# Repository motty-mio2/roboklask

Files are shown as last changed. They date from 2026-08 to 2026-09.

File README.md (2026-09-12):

# 🏓 Roboklask: Autonomous AI-Powered Klask-Playing Robot

English | [日本語](./README_ja.md)







Roboklask is an autonomous, real-time robotics system designed to play **Klask**—a fast-paced, magnetic table hockey game. Combining high-speed computer vision, an ONNX-optimized reinforcement learning agent (PPO), and low-latency motor control, Roboklask plays autonomously against human opponents.

[**👉 日本語版のREADMEはこちら (README_ja.md)**](./README_ja.md)

---

## 📸 Demo & Hardware Overview

*(Place your robot gameplay video or GIF here!)*
Roboklask Table and Striker Concept

### The Hardware Setup
* **Structure**: Custom 2D H-bot XY Gantry.
* **Actuators**: High-torque NEMA 17 Stepper Motors driven by DRV8825 motor drivers (configured at 1/8 microstepping).
* **Brain**: Arduino UNO R4 WiFi running Zephyr RTOS.
* **Vision**: OAK-D (DepthAI) or Intel RealSense stereo cameras capturing the table dynamics at 30+ FPS.

---

## ✨ Features

- 🧠 **PPO Reinforcement Learning**: Runs real-time inference on a Proximal Policy Optimization model (`klask_ppo_model.onnx`) via ONNX Runtime to make movement decisions.
- ⚡ **Low-Latency step control**: Powered by Zephyr RTOS, achieving step frequencies of up to **16,000 steps/sec** with **25,600 steps/sec²** acceleration.
- 🔌 **Unified MessagePack-RPC**: Low-overhead serial communication running at 30Hz, passing targets and receiving coordinate feedback synchronously.
- 🎯 **Robust Computer Vision**: Real-time HSV-based blue color tracking that automatically calibrates itself to detect the board, ball, and striker under dark lighting conditions.
- 🛡️ **Auto-Recalibration**: Dynamic limit switch detection (`resetX`/`resetY`) that recalibrates coordinate origins on the fly without stopping the game.

---

## 🛠️ System Architecture

```mermaid
graph TD
    A[Camera: OAK-D / RealSense] -->|Raw Video Frames| B(Python Vision Tracker)
    B -->|HSV Coordinate Extraction| C(Motion Policy: Ball Tracking / PPO Model)
    C -->|Target Coords: X,Y | D(McuConnection / BridgeDriver)
    D -->|MessagePack-RPC @ 30Hz| E[Arduino UNO R4 WiFi / Zephyr RTOS]
    E -->|High Frequency step pulses| F[Motors: NEMA 17 / DRV8825]
    E -->|Encoder Feedback @ 30Hz| D
```

> [!TIP]
> For a detailed look at our RTOS optimizations, serial-buffer flushing, and kinematics math, see the **[Technical Optimizations & Engineering Details](./docs/optimizations.md)** document.

---

## 💻 Quickstart (Arduino App Lab)

Simply open this project in Arduino App Lab!

## 🛠️ Alternative Setup (For Debugging / Development)

This project uses [mise](https://mise.jdx.dev/) as a polyglot task runner and environment manager.

### 1. Installation
Clone the repository and sync python dependencies:
```sh
git clone https://github.com/motty-mio2/roboklask.git
cd roboklask/python
uv sync
```

### 2. Compile and Upload Firmware
Compile the C++ Arduino sketch:
```sh
cd ../sketch
mise run build
```

### 3. Run the AI Agent
Start the vision loop (requires a camera and serial connection):
```sh
cd ../python
uv run python run_vision.py
```

### 4. Run Formatting & Lints
Keep the codebase clean:
```sh
mise run format   # Format Python & C++ source files
mise run lint     # Strict C++ static analysis and python type checks
```

---

## 📁 Repository Structure

- **[`sketch/`](./sketch/)** — Arduino C++ firmware targeting Arduino UNO R4 (UNO Q / Minima) for dual stepper motor control and sensor integration.
- **[`python/`](./python/)** — Python companion app (Python 3.13) for vision tracking (OAK-D / RealSense), motion policy inference (PPO / Ball tracking), and web UI.
- **[`hardware/`](./hardware/)** — 3D printable mechanical parts and mount designs.
  - **[Hardware & 3D Printing Guide](./hardware/HardWare.md)** ([日本語版](./hardware/HardWare_ja.md))
- **[`docs/`](./docs/)** — Technical engineering documentation and RTOS optimization details.

## 📚 Documentation

- **[Hardware & 3D Printing Guide](./hardware/HardWare.md)**: STL files, recommended BambuLab P1S print settings, and parts list.
- **[Python Package Documentation](./python/README.md)**: Setup and usage for the vision tracking and motion control application.
- **[Technical Optimizations & Engineering Details](./docs/optimizations.md)**: RTOS optimizations, serial-buffer flushing, and kinematics math.

## 🔗 Related Repositories

- [Klask_PCB](https://github.com/motty-mio2/Klask_PCB): Custom designed shield for Arduino UNO Q
- [Klask Vision](https://github.com/motty-mio2/Klask_vision): Computer vision inference package for Klask
  - [Klask Vision Learning](https://github.com/motty-mio2/Klask_vision_learning): Training pipeline for Klask vision models
- [Klask RL](https://github.com/motty-mio2/Klask_RL): Reinforcement learning agent for Klask

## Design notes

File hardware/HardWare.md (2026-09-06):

# Hardware

[English](HardWare.md) | [日本語](HardWare_ja.md)

This document provides information on 3D-printable hardware models and printing guidelines.  
The images show the **recommended print orientation** on the build plate in the slicer.

## Recommended Print Settings (BambuLab P1S)

All parts, except for the motor mounts, can be printed using the common settings.

### 1. Common Settings (All parts except Motor Mounts)

Based on the Bambu Studio standard preset **`0.20mm Standard`** with support enabled.

- **Recommended Material**: PLA
- **Base Preset**: `0.20mm Standard`
- **Supports**:
  - **Enable Support**: ON
  - **Type**: **Tree**
  *(Automatic tree support ensures stable printing even for parts with overhangs)*

### 2. Motor Mount Settings

Uses the Bambu Studio standard preset **`0.20mm Strength`**. Wall loops and infill density are preconfigured for structural strength.

- **Recommended Material**: PETG or ABS (recommended due to motor clamping torque, vibrations, and mechanical stress)
- **Base Preset**: `0.20mm Strength`
- **Supports**:
  - **Enable Support**: ON (Tree support recommended)
  - Using Bambu Lab support filament (e.g., Support for PLA/PETG) makes the interface layer easy to remove and ensures a clean finish.

---

## 3D Printed Parts List

| Part Name | File |  Qty  | Print Setting (Preset) | Notes |
| :--- | :--- | :---: | :---: | :--- |
| **RealSense Mount** | [RealSenseMounter.stl](./RealSenseMounter.stl) | 1 | 0.20mm Standard (Tree) | No support needed |
| **Camera Holder Jig**  | [CameraAngle.stl](./CameraAngle.stl) | 2 | 0.20mm Standard (Tree) | No support needed |
| **Motor Mount L** | [MotorMount_L.stl](./MotorMount_L.stl) | 1 |  **0.20mm Strength** | PETG/ABS recommended, support material recommended |
| **Motor Mount R** | [MotorMount_R.stl](./MotorMount_R.stl) | 1 |  **0.20mm Strength** | PETG/ABS recommended, support material recommended |
| **Leg** | [Leg.stl](./Leg.stl) | 2 | 0.20mm Standard (Tree) | No support needed |
| **Limit Switch Mount** | [LimitSwitchMount.stl](./LimitSwitchMount.stl) | 1 | 0.20mm Standard (Tree) | No support needed |
| **Pulley Mount A_L** | [PulleyMountA_L.stl](./PulleyMountA_L.stl) | 1 | 0.20mm Standard (Tree) | - |
| **Pulley Mount A_R** | [PulleyMountA_R.stl](./PulleyMountA_R.stl) | 1 | 0.20mm Standard (Tree) | - |
| **Pulley Mount B** | [PulleyMountB.stl](./PulleyMountB.stl) | 1 | 0.20mm Standard (Tree) | - |
| **Pulley Mount C** | [PulleyMountC.stl](./PulleyMountC.stl) | 1 | 0.20mm Standard (Tree) | - |
| **Arm Holder** | [Arm_Holder.stl](./Arm_Holder.stl) | 1 | 0.20mm Standard (Tree) | Significant supports, support material strongly recommended |
| **Stopper** | [Stopper.stl](./Stopper.stl) | 2 | 0.20mm Standard (Tree) | No support needed |

---

## Part Details

### Camera

- [RealSense Mount](./RealSenseMounter.stl)
  - Quantity: 1
  - Setting: Common Settings
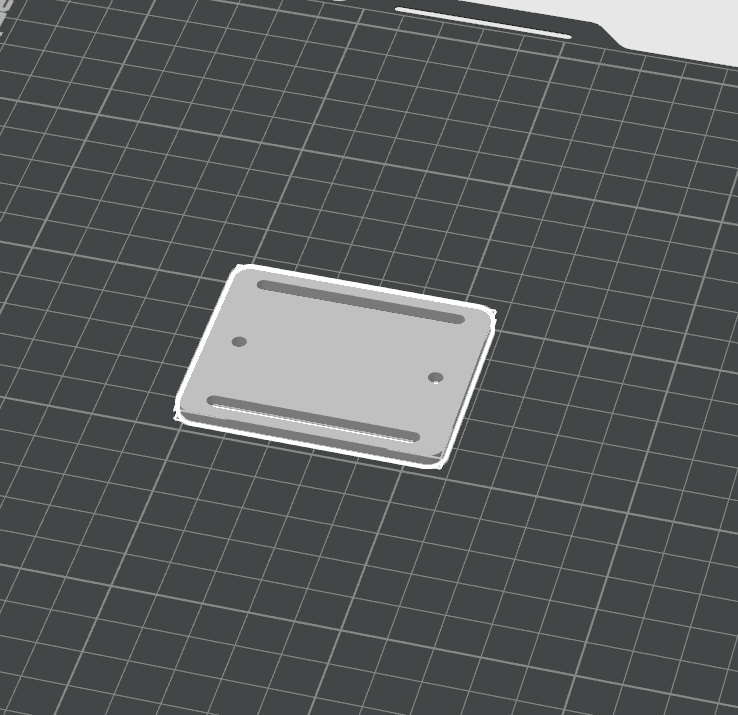
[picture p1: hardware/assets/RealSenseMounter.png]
RealSense Mount
  
  
- [Camera Holder Jig](./CameraAngle.stl)
  - Quantity: 2
  - Setting: Common Settings
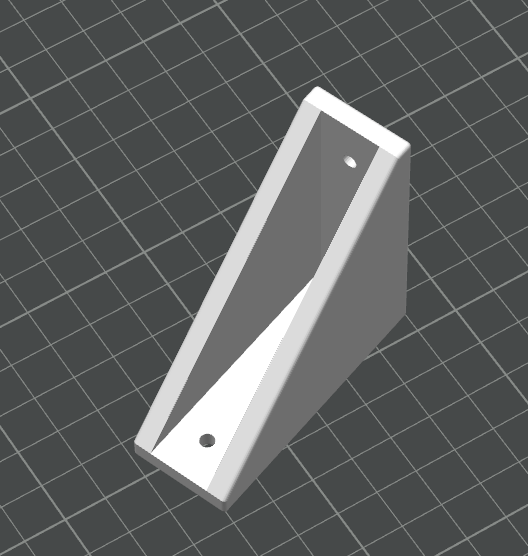
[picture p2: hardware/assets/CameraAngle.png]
Camera Holder Jig
  
  
### Main Body

- Motor Mounts
  - [MotorMount_L.stl](./MotorMount_L.stl) (Left: 1)
  - [MotorMount_R.stl](./MotorMount_R.stl) (Right: 1)
  - Setting: **Motor Mount Settings (0.20mm Strength)**
  - Due to mechanical load, we recommend higher infill density or strong filament such as ABS or PETG.
  - Using Bambu Lab support filament helps achieve a clean finish.
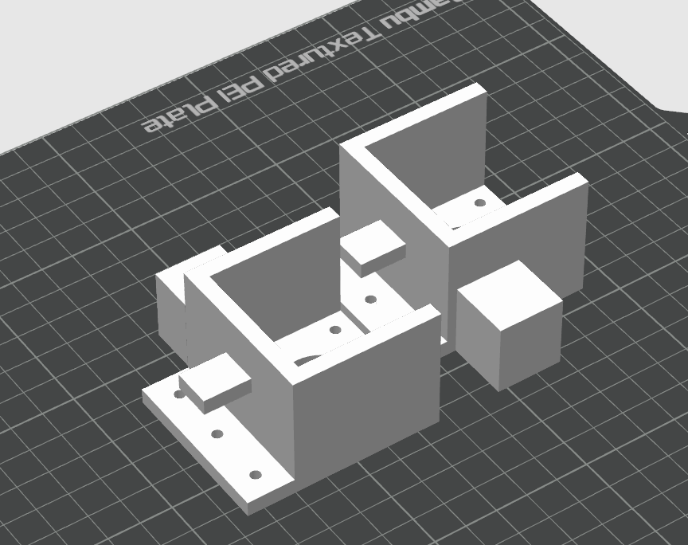
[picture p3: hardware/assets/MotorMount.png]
Motor Mount
  
  
- [Leg](./Leg.stl)
  - Quantity: 2
  - Setting: Common Settings
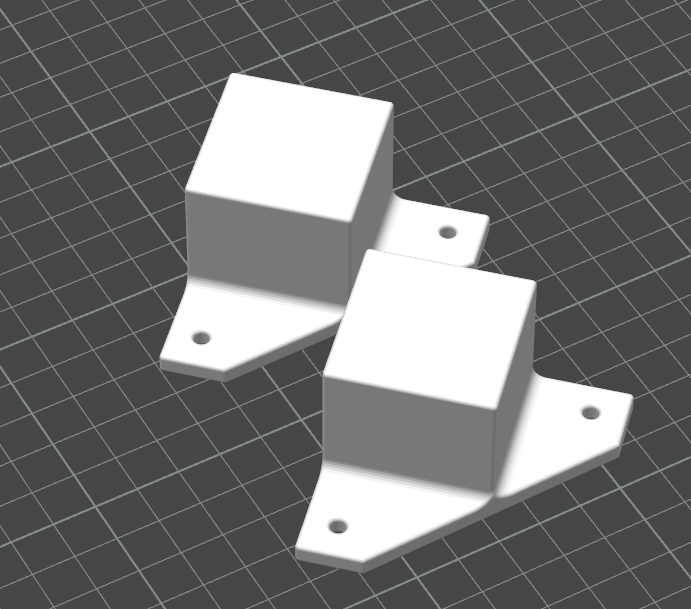
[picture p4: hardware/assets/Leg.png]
Leg
  
  
- [Limit Switch Mount](./LimitSwitchMount.stl)
  - Quantity: 1
  - Setting: Common Settings
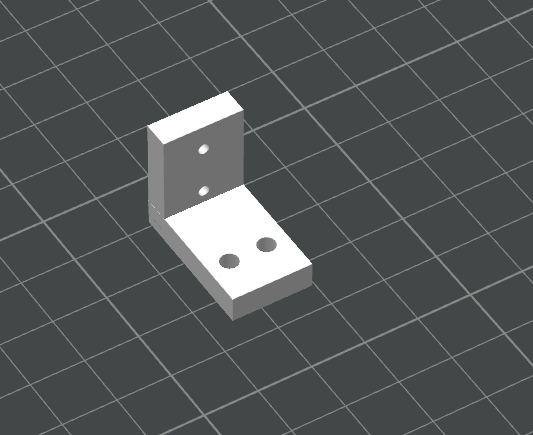
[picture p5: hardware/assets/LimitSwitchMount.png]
Limit Switch Mount
  
  
- Pulley Mounts
  - [PulleyMountA_L.stl](./PulleyMountA_L.stl) (1)
  - [PulleyMountA_R.stl](./PulleyMountA_R.stl) (1)
  - [PulleyMountB.stl](./PulleyMountB.stl) (1)
  - [PulleyMountC.stl](./PulleyMountC.stl) (1)
  - Setting: Common Settings
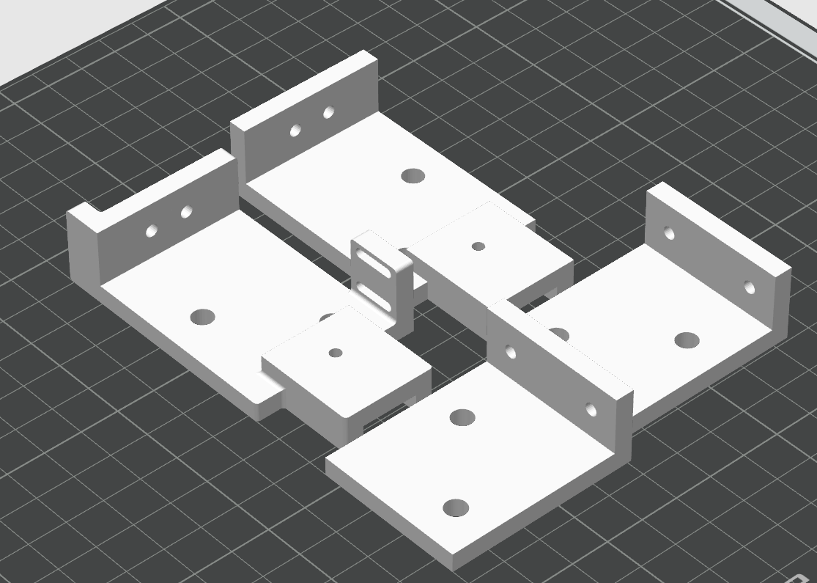
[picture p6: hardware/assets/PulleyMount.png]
Pulley Mount
  
  
- [Arm Holder](./Arm_Holder.stl)
  - Quantity: 1
  - Setting: Common Settings
  - Generates a large amount of supports.
  - Support filament is strongly recommended.
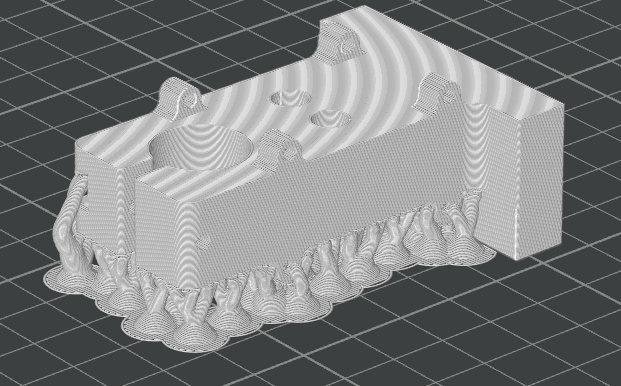
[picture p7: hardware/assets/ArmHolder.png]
Arm Holder
  
  
- [Stopper](./Stopper.stl)
  - Quantity: 2
  - Setting: Common Settings
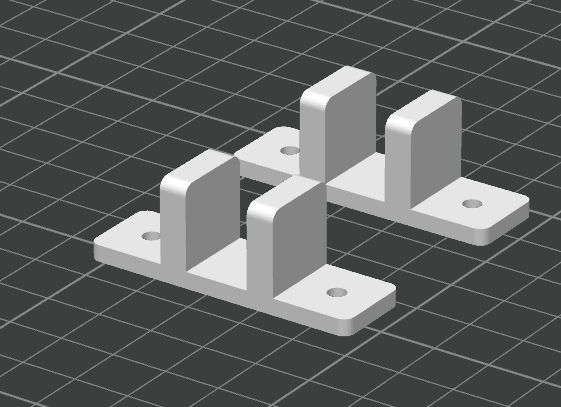
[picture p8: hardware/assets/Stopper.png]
Stopper


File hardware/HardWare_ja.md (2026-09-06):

# ハードウェアについて

[English](HardWare.md) | [日本語](HardWare_ja.md)

ここには、3Dプリントするハードウェアのモデルデータおよび印刷情報を記載します。  
掲載している各パーツの画像は、スライサーでの**推奨する印刷の向き**を示しています。

## 推奨印刷設定（BambuLab P1S）

モータマウンタ以外のパーツは、すべて共通の設定で印刷可能です。

### 1. 共通設定（モータマウンタ以外）

Bambu Studio の標準プリセット **`0.20mm Standard`** をベースにし、サポート設定のみ追加しています。

- **推奨素材**: PLA
- **ベースプリセット**: `0.20mm Standard`
- **サポート**:
  - **サポート有効化**: ON
  - **タイプ**: **ツリー（Tree）**
  *(※オーバーハングがある形状も自動ツリーサポートで安定して印刷できます)*

### 2. モータマウンタ設定

Bambu Studio の標準プリセット **`0.20mm Strength`** を使用します。壁ループ数やインフィルがあらかじめ強度重視に設定されています。

- **推奨素材**: PETG または ABS（モータの締め付けや振動・負荷がかかるため高強度フィラメントを推奨）
- **ベースプリセット**: `0.20mm Strength`
- **サポート**:
  - **サポート有効化**: ON（ツリーサポート推奨）
  - BambuLabのサポート用フィラメント（Support for PLA/PETG等）を使用すると、インターフェース層が剥がしやすく美しく仕上がります

---

## 3Dプリントパーツ一覧

| 部品名 | ファイル | 数量  |  印刷設定（プリセット）  | 特記事項 |
| :--- | :--- | :---: | :---: | :--- |
| **RealSenseマウンタ** | [RealSenseMounter.stl](./RealSenseMounter.stl) | 1 | 0.20mm Standard (ツリー) | サポート不要 |
| **カメラホルダー治具** | [CameraAngle.stl](./CameraAngle.stl) | 2 | 0.20mm Standard (ツリー) | サポート不要 |
| **モータマウンタ L** | [MotorMount_L.stl](./MotorMount_L.stl) | 1 | **0.20mm Strength** | PETG/ABS推奨・サポート材推奨 |
| **モータマウンタ R** | [MotorMount_R.stl](./MotorMount_R.stl) | 1 | **0.20mm Strength** | PETG/ABS推奨・サポート材推奨 |
| **脚** | [Leg.stl](./Leg.stl) | 2 | 0.20mm Standard (ツリー) | サポート不要 |
| **リミットスイッチマウント** | [LimitSwitchMount.stl](./LimitSwitchMount.stl) | 1 | 0.20mm Standard (ツリー) | サポート不要 |
| **プーリーマウント A_L** | [PulleyMountA_L.stl](./PulleyMountA_L.stl) | 1 | 0.20mm Standard (ツリー) | - |
| **プーリーマウント A_R** | [PulleyMountA_R.stl](./PulleyMountA_R.stl) | 1 | 0.20mm Standard (ツリー) | - |
| **プーリーマウント B** | [PulleyMountB.stl](./PulleyMountB.stl) | 1 | 0.20mm Standard (ツリー) | - |
| **プーリーマウント C** | [PulleyMountC.stl](./PulleyMountC.stl) | 1 | 0.20mm Standard (ツリー) | - |
| **アームホルダー** | [Arm_Holder.stl](./Arm_Holder.stl) | 1 | 0.20mm Standard (ツリー) | サポート多・サポート材推奨 |
| **ストッパー** | [Stopper.stl](./Stopper.stl) | 2 | 0.20mm Standard (ツリー) | サポート不要 |

---

## 各パーツ詳細

### カメラ系

- [RealSenseマウンタ](./RealSenseMounter.stl)
  - 数量: 1つ
  - 設定: 共通設定
  RealSenseマウンタ
  
- [カメラホルダー治具](./CameraAngle.stl)
  - 数量: 2つ
  - 設定: 共通設定
  カメラホルダー治具
  
### 本体系

- モータマウンタ
  - [MotorMount_L.stl](./MotorMount_L.stl) (L側: 1つ)
  - [MotorMount_R.stl](./MotorMount_R.stl) (R側: 1つ)
  - 設定: **モータマウンタ設定（0.20mm Strength）**
  - 力がかかるため、インフィル密度を高くするか、ABSやPETGなどの強度のあるフィラメントを使用することを推奨します
  - BambuLabのサポート用フィラメントがあると美しく仕上がります
  モータマウンタ
  
- [脚](./Leg.stl)
  - 数量: 2つ
  - 設定: 共通設定
  脚
  
- [リミットスイッチマウント](./LimitSwitchMount.stl)
  - 数量: 1つ
  - 設定: 共通設定
  リミットスイッチマウント
  
- プーリーマウント
  - [PulleyMountA_L.stl](./PulleyMountA_L.stl) (1つ)
  - [PulleyMountA_R.stl](./PulleyMountA_R.stl) (1つ)
  - [PulleyMountB.stl](./PulleyMountB.stl) (1つ)
  - [PulleyMountC.stl](./PulleyMountC.stl) (1つ)
  - 設定: 共通設定
  プーリーマウント
  
- [アームホルダー](./Arm_Holder.stl)
  - 数量: 1つ
  - 設定: 共通設定
  - サポートの分量が非常に多くなります
  - サポート用フィラメントの使用を強く推奨します
  アームホルダー
  
- [ストッパー](./Stopper.stl)
  - 数量: 2つ
  - 設定: 共通設定
  ストッパー

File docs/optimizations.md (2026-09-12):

# Roboklask: Technical Optimizations & Engineering Details

This document covers the deep technical optimizations implemented in the Roboklask firmware, communication bridge, and runtime scheduler.

---

## 1. High-Frequency Step Generation (Zephyr RTOS)

### The Challenge
Standard Arduino environments run `loop()` sequentially. In RTOS-based cores (like Zephyr RTOS on Arduino UNO R4), returning from `loop()` triggers system-level thread rescheduling, serial polling, and hardware events. This introduces a background overhead of **200µs to 1ms** per iteration.

Because `AccelStepper` relies on a polling architecture (`stepper.run()`), it must be called at a frequency higher than the required step pulse frequency. With a target operational speed of **16,000 steps/second** (at 1/8 microstepping), the minimum polling frequency must exceed **30kHz**. Polling inside a standard `loop()` limited to 1kHz due to core overhead restricts the motor speed to a crawl (under 2,000 steps/sec).

### The Optimization
We bypassed the Arduino core's `loop()` return overhead by encapsulating the execution inside an internal infinite `while(true)` loop:

```cpp
void loop() {
  unsigned long last_yield_ms = 0;

  while (true) {
    // 1. Poll stepper motors at max CPU frequency (~100kHz)
    xyControl.run();

    unsigned long current_time = millis();

    // 2. Manage 33ms control cycles with guard clauses
    if (current_time - last_update_ms < CYCLE_ms) {
      #if defined(ARDUINO_UNO_Q)
      if (Serial1.available() > 0) {
        safeUpdate();
      }
      // Thread Starvation Guard: Yield exactly once per millisecond
      if (current_time - last_yield_ms >= 1) {
        last_yield_ms = current_time;
        k_yield();
      }
      #endif
      continue;
    }
    last_update_ms = current_time;

    // 3. Execute 33ms periodic logic (target coordinates, matrix rendering)
    ...
  }
}
```

* **Result**: Step polling frequency increased from ~1kHz to **~100kHz**, unlocking the full potential of the NEMA 17 steppers to run smoothly at **16,000 steps/sec** with an acceleration profile of **25,600 steps/sec²**.
* **Thread Safety**: Calling `k_yield()` once every 1ms ensures that Zephyr's network and system threads get their time slices, preventing any hardware lockups.

---

## 2. Low-Latency RPC over MessagePack-RPC

### The Challenge
Initially, the Python tracker sent separate RPC notifications for target striker positions (`py2mcu`) and target ball positions (`ball`) at 30Hz. This generated **60 packets/second** over the 115200bps serial port. The overhead of serial packet parsing and deserialization on the MCU created a queue bottleneck: when the python sender stopped, the robot continued to move for several seconds (queued command latency).

### The Optimization
1. **Consolidated Payload**: We merged the target coordinate and the ball coordinates into a single MessagePack-RPC call:
   ```python
   # Python Driver
   self.bridge.notify("py2mcu", target.x, target.y, ball.x, ball.y)
   ```
2. **Synchronous Buffer Flushing (`safeUpdate`)**: Instead of relying on Zephyr's asynchronous service thread to deserialize packets, the main loop detects data in the buffer (`Serial1.available() > 0`) and triggers `safeUpdate()` synchronously.
3. **Step-Level Change Detection**:
   Floating-point coordinate values fluctuate slightly due to camera noise (e.g., `0.0001` variance). Overwriting the target via `stepper.moveTo()` resets AccelStepper's acceleration planner. We wrapped the target setter to only execute `moveTo()` when the actual physical target steps change:
   ```cpp
   long target_s1 = (target_step_x + target_step_y) * resolution;
   long target_s2 = (-target_step_x + target_step_y) * resolution;

   if (target_s1 != last_target_s1 || target_s2 != last_target_s2) {
     stepper1.moveTo(target_s1);
     stepper2.moveTo(target_s2);
     last_target_s1 = target_s1;
     last_target_s2 = target_s2;
   }
   ```
* **Result**: Latency accumulation is completely eliminated. The robot tracking response matches the 33ms vision loop instantaneously.

---

## 3. Kinetic Safety & Boundary Calibration

### The Challenge
Homing absolute coordinates via raw step offsets can lead to physical limit switch crashes if the two motors run slightly out of sync. Furthermore, keeping the striker away from physical limit walls reduces its playable range.

### The Optimization
* **Relative Target Homing**: Homing steps are commanded via relative movements (`move()`) rather than absolute targets (`moveTo()`). This guarantees that both H-bot motors receive identical step pulses, keeping the carriage perfectly straight during homing.
* **Separation of Safety Margins**:
  We separated the physical release limit (`PHYSICAL_BACK = 300` steps) from the software play boundary limit (`STEP_BACK_X`, `STEP_BACK_Y = 100` steps).
  ```cpp
  constexpr int XSTEP = 3100 * 2 + 500 - STEP_BACK_X * 2;
  constexpr int YSTEP = 1500 * 2 + 100 - STEP_BACK_Y;
  ```
  This maximizes the playable area (`XSTEP=2900`, `YSTEP=1400`) while allowing the robot to calibrate its zero-point exactly `100` steps away from the physical switches.
* **Dynamic Recalibration & Non-Blocking Escape**: If a limit switch is triggered mid-game, the robot immediately stops and executes a backing-off routine (`escapeX/Y` by `PHYSICAL_BACK` steps). During this backing-off `while` loop, the code actively processes serial communications (`safeUpdate()`) and yields thread control (`k_yield()`) to prevent the Zephyr RTOS communication stacks from starving and dropping the connection. Afterwards, the MCU recalculates and overrides the absolute coordinates on the fly (`resetX/Y`) seamlessly.

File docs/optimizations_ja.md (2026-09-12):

# Roboklask: 技術解説 ＆ 最適化詳細

本文書では、Roboklask のファームウェア、通信ブリッジ、およびランタイムスケジューラに実装されている深い技術的最適化について解説します。

---

## 1. Zephyr RTOS 上での極限の超低遅延・高頻度ステップパルス生成

### 課題
標準の Arduino 環境は、単一スレッドで `loop()` をシーケンシャルにループ実行します。しかし、Zephyr RTOS などの OS 上で動作する Arduino コア（Arduino UNO R4 WiFi など）では、`loop()` が `return` して再実行されるまでの間に、システムスレッドの再スケジューリング、シリアルポートのポーリング、その他のハードウェア管理など、**200µs〜1ms 程度のオーバーヘッド**が発生します。

ステップ更新ライブラリ `AccelStepper` は、ポーリング制御モデル（`stepper.run()`）を採用しているため、目標のステップ出力周波数よりも大幅に高い頻度でポーリングする必要があります。1/8ステップ解像度で最大速度 **16,000 steps/sec** を出すためには、最低でも **30kHz 以上**の頻度で `run()` を呼ぶ必要があります。しかし、コアのオーバーヘッドのせいで `loop()` の周回が 1kHz 程度に制限されると、モーター速度は 2,000 steps/sec 未満（這うような遅さ）に頭打ちになってしまいます。

### 解決策
`loop()` の `return` に伴う Arduino コア側のオーバーヘッドを完全に回避するため、`loop()` の内部を **`while(true)` による無限ポーリングループ** にリファクタリングしました。

```cpp
void loop() {
  unsigned long last_yield_ms = 0;

  while (true) {
    // 1. CPUの限界周波数（約100kHz）でステッピングモーターを更新
    xyControl.run();

    unsigned long current_time = millis();

    // 2. 33msに満たない場合は、即座に continue してループ先頭に戻る
    if (current_time - last_update_ms < CYCLE_ms) {
      #if defined(ARDUINO_UNO_Q)
      if (Serial1.available() > 0) {
        safeUpdate();
      }
      // スレッド飢餓防止ガード: 1msに1回だけ OS に処理を明け渡す
      if (current_time - last_yield_ms >= 1) {
        last_yield_ms = current_time;
        k_yield();
      }
      #endif
      continue;
    }
    last_update_ms = current_time;

    // 3. 33ms 周期のメイン制御処理を実行
    ...
  }
}
```

* **結果**: ステップのポーリング周波数が ~1kHz から **~100kHz** へと跳ね上がり、NEMA 17 ステッピングモーターの限界値である **`16,000 steps/sec` (秒速約200mm) の最高速度** と、**`25,600 steps/sec²` の加速度** を一切引っかかることなく滑らかに引き出せるようになりました。
* **スレッド安全性**: 1msに1回だけ `k_yield()` を呼び出すことで、Zephyr RTOS のネットワークやシリアル処理のシステムタスクが確実に実行時間を割り当てられ、ハングアップを完璧に防止しています。

---

## 2. MessagePack-RPC を介した低遅延 RPC 通信の実現

### 課題
当初、Python側のトラッカーは、目標ストライカー座標（`py2mcu`）と目標ボール座標（`ball`）を別々の RPC 通知として 30Hz 周期で送信していました。これは、115200bps のシリアル通信回線上で **毎秒 60 パケット** を処理することを意味します。マイコン側でのパケット受信・デシリアライズ処理のオーバーヘッドにより受信バッファにパケットが滞留し、Python側の送信を停止してもしばらくロボットが遅れて動き続ける「キューイング遅延（数秒レベル）」が発生していました。

### 解決策
1. **パケットの統合**: 目標座標とボール座標を単一の MessagePack-RPC 呼び出しに統合し、通信パケット数を半減させました。
   ```python
   # Python Driver
   self.bridge.notify("py2mcu", target.x, target.y, ball.x, ball.y)
   ```
2. **同期バッファフラッシュ (`safeUpdate`)**: 非同期スレッドのタスク切り替えによる受信遅延を防ぐため、メインループ内でシリアルデータがあること (`Serial1.available() > 0`) を検知し、同期的に `safeUpdate()` を実行するようにしました。
3. **ステップ数レベルの変化検知フィルタ**:
   カメラの画像認識ノイズ（`0.0001` 程度の微小な座標変動）によって毎サイクル目標座標が書き換わると、`stepper.moveTo()` を呼ぶたびに `AccelStepper` の加減速プロファイルプランナーが再計算されてリセットされてしまいます。これを防ぐため、物理的な「目標ステップ数」が実際に変化したときだけ `moveTo()` を呼ぶガードをクラス内部に組み込みました。
   ```cpp
   long target_s1 = (target_step_x + target_step_y) * resolution;
   long target_s2 = (-target_step_x + target_step_y) * resolution;

   if (target_s1 != last_target_s1 || target_s2 != last_target_s2) {
     stepper1.moveTo(target_s1);
     stepper2.moveTo(target_s2);
     last_target_s1 = target_s1;
     last_target_s2 = target_s2;
   }
   ```
* **結果**: 通信起因の遅延が完全に消失し、ロボットの追従性が Python 側の 33ms 制御周期と完全に同期するようになりました。

---

## 3. 安全機構（Kinetic Safety） ＆ 境界キャリブレーション

### 課題
H-bot リンク機構において、絶対座標の指定のみでホーミングを行うと、左右のモーターのパルス出力のわずかな非対称によってキャリッジが斜めに傾き、リミットスイッチに衝突するリスクがあります。また、壁からの安全マージンが大きすぎると、ストライカーの盤面での可動域が狭くなってしまいます。

### 解決策
* **相対座標によるホーミング**: ホーミング時の移動には絶対座標指定（`moveTo`）ではなく、相対座標（`move()`）を使用しました。これにより、2つのモーターに完全に同一のステップパルス数が供給され、キャリッジが一切傾くことなくまっすぐ前後に直進します。
* **物理限界とソフト境界マージンの分離**:
  スイッチ衝突から安全に離脱するための物理的な戻り量（`PHYSICAL_BACK = 300` ステップ）と、ゲームのプレイ境界を制限するソフトウェアマージン（`STEP_BACK_X`/`Y = 100` ステップ）を分離定義しました。
  ```cpp
  constexpr int XSTEP = 3100 * 2 + 500 - STEP_BACK_X * 2;
  constexpr int YSTEP = 1500 * 2 + 100 - STEP_BACK_Y;
  ```
  これにより、ソフトウェア原点 `0` はスイッチから 100 ステップ離れた安全な位置にありつつ、プレイ領域自体は限界の広さ（`XSTEP=2900`, `YSTEP=1400`）を確保することができました。
* **動的再キャリブレーション ＆ ノンブロッキング離脱**: プレイ中に激突を検知した場合、システムをシャットダウンするのではなく、安全方向への退避動作（`PHYSICAL_BACK`ステップ分の `escapeX/Y` 移動）を実行します。この退避中の `while` ループ内でもシリアル通信の処理（`safeUpdate()`）と RTOS のスレッド明け渡し（`k_yield()`）を継続して実行することで、退避移動中も Python 側との通信切断やハングを完全に防止しています。離脱完了後、その場で絶対座標を動的に再計算して `setCurrentPosition()` で上書きし、ゲームを中断せずに復帰します。

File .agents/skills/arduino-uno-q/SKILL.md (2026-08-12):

---
name: arduino-uno-q
description: Arduino UNO Q (UNO R4 / Minima) ボード開発、MPU-MCU間の通信、App Lab、App Bricks、および Bridge API についての知識と手順を提供します。
---

# SKILL.md: Arduino UNO Q

## 概要
このスキルは、Arduino UNO Q ボードにおける開発基盤、特に Linux マイクロプロセッサ (MPU) と Arduino マイクロコントローラ (MCU) 間を連携させる Bridge API、およびボード固有の実装手順を提供します。

---

## 1. 接続方式の選択 (UNO Q vs Minima)
本プロジェクトでは、対象となるターゲットボードに応じて通信および運動制御ポリシーのレイヤーが異なります。

* **UNO R4 (UNO Q / Zephyr RTOS)**:
  * **通信方式**: `Bridge` 通信 (MessagePack RPC)
  * **設定**: `KLASK_OUTPUT_TYPE=bridge`
  * **特徴**: Zephyr RTOS カーネル上で動作し、LEDマトリクス表示、および Bridge API による非同期・同期RPCを利用します。
* **Minima (Arduino UNO R4 Minima)**:
  * **通信方式**: UART シリアル通信 (115200 baud)
  * **設定**: `KLASK_OUTPUT_TYPE=uart`
  * **特徴**: リアルタイム処理ループで UART の特定ヘッダー (`0xAA`) に基づくバイナリパケットを直接処理します。

---

## 2. MCU 側 (C++ スケッチ) の Bridge 実装手順

UNO Q で Bridge 通信を行う場合、以下の手順とテンプレートに従って実装します。

### 実装テンプレート
```cpp
#include <Arduino_RouterBridge.h>
#include <zephyr/kernel.h> // Zephyr カーネルのヘッダー

// 共有データアクセス用のミューテックスを定義
K_MUTEX_DEFINE(xy_mutex);

struct Position {
  float x;
  float y;
} new_head_pos, head_pos;

unsigned long lastReportMs = 0;

void setup() {
  // Bridge APIの初期化
  Bridge.begin();

  // Python(MPU)側から呼び出されるRPC/通知のコールバック登録
  Bridge.provide("xy", [](float x, float y) {
    // コールバックは別スレッドで実行されるため、必ずロックを取得する
    k_mutex_lock(&xy_mutex, K_FOREVER);
    new_head_pos.x = x;
    new_head_pos.y = y;
    k_mutex_unlock(&xy_mutex);
  });

  Monitor.begin();
}

void loop() {
  // 共有変数を安全にローカルにコピーして利用する
  Position local_target;
  k_mutex_lock(&xy_mutex, K_FOREVER);
  local_target = new_head_pos;
  k_mutex_unlock(&xy_mutex);

  // 運動制御への適用など
  // xyControl.move(local_target);

  // Python(MPU)側への周期的な座標通知 (非ブロッキングで20ms周期を維持)
  unsigned long now = millis();
  if (now - lastReportMs >= 20) {
    lastReportMs = now;
    // MPU側の report_xy プロバイダを呼び出す
    Bridge.call("report_xy", head_pos.x, head_pos.y);
  }
}
```

### 【重要】マルチスレッドとスレッドセーフティ
* **RPC コールバックのスレッド**: `Bridge.provide` で登録されたコールバックは、メインの `loop()` とは異なるスレッド（Bridge サービススレッド）で実行されます。
* **排他制御**: `loop()` 内とコールバック内で共有されるすべての変数（例: ターゲット座標など）は、Zephyr カーネルのプリミティブである `K_MUTEX_DEFINE` マクロで定義した `k_mutex` を用いて、`k_mutex_lock` および `k_mutex_unlock` で保護してください。

---

## 3. MPU 側 (Python) の Bridge 実装手順

Python アプリケーション側では、`arduino-app-bricks` に含まれる Bridge API を使用して接続モジュールを実装します。

### 実装テンプレート (`bridge_connection.py` 相当)
```python
import threading
from arduino.app_utils import Bridge
from python.domain import RobotXY
from python.domain.mcu_connection import McuConnection

class BridgeMcuConnection(McuConnection):
    def __init__(self) -> None:
        self._lock = threading.Lock()
        self._latest_feedback: RobotXY | None = None

    def start(self) -> None:
        try:
            # MCUからの report_xy 呼び出しを処理するコールバックを登録
            Bridge.provide("report_xy", self._on_feedback)
        except Exception as e:
            print(f"Error starting bridge: {e}")

    def _on_feedback(self, x: float, y: float) -> None:
        # コールバックはサブスレッドから呼び出されるため threading.Lock で保護
        feedback = RobotXY(x=x, y=y)
        with self._lock:
            self._latest_feedback = feedback

    def send_target(self, target: RobotXY | None) -> None:
        if target is None:
            return
        try:
            # メインの画像処理・推論ループをブロックしないために notify (非同期RPC) を使用
            Bridge.notify("xy", target.x, target.y)
        except Exception as e:
            print(f"Error sending coordinates: {e}")

    def read_feedback(self) -> RobotXY | None:
        with self._lock:
            feedback = self._latest_feedback
            self._latest_feedback = None  # 読み取り後はリセット
        return feedback

    def stop(self) -> None:
        try:
            # コールバックの登録解除
            Bridge.unprovide("report_xy")
        except Exception as e:
            print(f"Error stopping bridge: {e}")
```

### 実装時の注意点
1. **ブロッキングの回避**: 座標送信には `Bridge.call` ではなく `Bridge.notify` を使用してください。`call` は応答を待機するため、20ms などの高速な画像処理ループ（メインスレッド）を停止させ、ジッターを発生させる原因になります。
2. **メッセージバッファ制限**: `arduino-router` 経由の RPC 送信メッセージサイズは最大 **256バイト** です。大量のデータや複雑な構造体を一度に送信しないでください。

---

## 4. リファレンスとドキュメント
* [Working with Arduino Router RPC | Arduino Documentation](https://docs.arduino.cc/tutorials/uno-q/routerbridge-multilanguage/)
* [Bridge API Reference | Arduino Documentation](https://docs.arduino.cc/software/app-lab/bridge/bridge-api/)
* [GitHub - arduino/app-bricks-examples](https://github.com/arduino/app-bricks-examples)

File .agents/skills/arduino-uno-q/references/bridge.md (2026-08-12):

# SKILL: Arduino UNO Q Bridge API

## 概要
Arduino UNO QのBridge APIは、Linuxマイクロプロセッサ（MPU）上のPythonロジックと、Arduinoマイクロコントローラ（MCU）上のリアルタイムなC++スケッチ間で双方向通信（RPC）を行うためのレイヤーです [1]。裏側では`arduino-router`サービスがMessagePack RPCプロトコルを用いてネットワークを管理しており、通信時の最大メッセージサイズは256バイトに制限されています [2]。

## API仕様詳細と制約

### 1. C++ API (MCU / Arduinoスケッチ側)
実装には `<Bridge.h>` をインクルードして使用します [3]。
*   **初期化**: `setup()` 関数内で他のBridgeメソッドを使用する前に `Bridge.begin()` を呼び出し、内部のシリアルトランスポートを初期化します [3]。
*   **送信 (Python関数の呼び出し)**:
    *   `Bridge.call("メソッド名", 引数...)`: Linux側の登録された関数を呼び出し、結果が返るまで実行をブロック（待機）します [3]。
    *   `Bridge.notify("メソッド名", 引数...)`: 応答を待たずに非同期でデータを送信（Fire-and-forget）します [4]。256バイトを超えたメッセージは破棄されます [4]。
*   **受信 (関数の公開)**:
    *   `Bridge.provide("名前", コールバック)`: 高優先度のバックグラウンドRPCスレッドで実行される関数を登録します [4]。処理は短くスレッドセーフである必要があります [4]。**警告**: デッドロックを防ぐため、このコールバック内部で `Bridge.call()` や `Monitor.print()` を使用してはいけません [5]。
    *   `Bridge.register("名前", コールバック)`: メインの `loop()` コンテキスト内で実行される関数を登録します [5]。`delay()` や `Wire` などの標準Arduino APIと連携する場合は、クラッシュを防ぐためにこちらを使用してください [5, 6]。

### 2. Python API (MPU / Linux側)
`bridge` モジュールから `Bridge` クラスをインポートして使用します [6]。
*   **送信 (MCU関数の呼び出し)**:
    *   `Bridge.call("メソッド名", 引数...)`: MCU側の関数を呼び出し、結果をブロックして待機します [6]。256バイト制限を超えると例外が発生します [6]。
    *   `Bridge.notify("メソッド名", 引数...)`: MCUの関数へ、応答を待たずに非同期で送信します [7]。
*   **受信 (関数の公開)**:
    *   `Bridge.register("タグ", コールバック)`: MCUからの要求に一致するタグを受け取った際に呼び出されるPython関数を登録します [7]。

### 3. データ型のマッピング (MsgPack)
Bridgeライブラリは、PythonとC++間のデータ型をMsgPackを使用して自動的にシリアライズ・デシリアライズします [8]。
*   Python `list` ⇔ C++ `std::vector`, `std::array`, `std::list` [8]
*   Python `dict` ⇔ C++ `std::map` [8]
*   Python `str` ⇔ C++ `char*`, `String` [8]
*   Python `bytes` ⇔ C++ `std::vector<uint8_t>`, `arduino::msgpack::arr_t<uint8_t>` [8]
*   Python `None` ⇔ C++ `void` [8]

### 4. Monitor API
従来のUSB CDCシリアルポート（`Serial.print`など）の代わりに、仮想シリアルモニターとして機能する Monitor API を使用します [8]。
*   `Monitor.begin()` で初期化します [9]。
*   `Monitor.print(データ)` や `Monitor.println(データ)` でシリアルモニターへデータを送信します [9]。
*   `Monitor.read()` で受信データを読み取りますが、現在のC++実装ではキューが空の場合、標準のStreamクラスと異なり **`-1` ではなく `0` を返す**仕様に注意してください [9]。

## References
*   [Bridge API Reference | Arduino Documentation](https://docs.arduino.cc/software/app-lab/bridge/bridge-api/)
*   [Working with Arduino Router RPC | Arduino Documentation](https://docs.arduino.cc/tutorials/uno-q/rou

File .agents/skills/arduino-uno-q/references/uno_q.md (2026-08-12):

# SKILL: Arduino UNO Q デバイス概要

## デバイスの概要
**Arduino UNO Q**は、高レベルな処理を担うLinuxマイクロプロセッサ（MPU）と、リアルタイム制御を担うArduinoマイクロコントローラ（MCU）を1つのボードに統合したシングルボードコンピュータです。このデュアルアーキテクチャプラットフォームにより、AIエッジアプリケーションなどに必要な高性能コンピューティングと、決定論的なリアルタイムハードウェア制御を同時に実現します。両プロセッサ間は、内蔵のRPCライブラリ（Arduino Bridge）とバックグラウンドで稼働する `arduino-router` デーモンによってシームレスに連携しています。

## プロセッサ (MPU / MCU)
UNO Qは、それぞれ以下の高性能な専用プロセッサを搭載しています。

*   **MPU (Microprocessor Unit)**: **Qualcomm Dragonwing™ QRB2210**
    *   **仕様**: Quad-core Arm® Cortex®-A53 (2.0 GHz)。
    *   **特徴**: Adreno GPU 3Dグラフィックスアクセラレータ、デュアルISP (13 MP + 13 MP または 25 MP @ 30 fps) などを備えています。主にPythonアプリケーション、AIモデル、高度なロジック処理を担います。
*   **MCU (Microcontroller Unit)**: **STMicroelectronics STM32U585**
    *   **仕様**: 32-bit Arm® Cortex®-M33 (最大 160 MHz)。
    *   **特徴**: 2 MBのフラッシュメモリ、786 kBのSRAM、浮動小数点演算ユニット（FPU）を搭載しています。センサーからのデータ読み取りやモーター制御など、リアルタイムなArduinoスケッチ（C++）を遅延なく実行します。

## オペレーティングシステム (OS)
*   **MPU側 (Linux)**: **Debian Linux OS**。
    MPU上では、アップストリームサポートを備えた**完全なDebianベースのLinux環境**が組み込まれて稼働しています。開発者は馴染みのあるLinux環境でそのまま開発を行うことが可能であり、スタンドアロンのPCのようにも扱えます。
    *※注意: ソース文献内では単に「Debian Linux」とのみ記載されており、ご指定の「Debian 13」という具体的なメジャーバージョンについては言及されていません。*
*   **MCU側 (Arduino / Zephyr)**: **Zephyr OS**。
    MCU側にデプロイされるArduinoスケッチは、**リアルタイムOSであるZephyr OS上で動作**します。これにより、クリティカルなタイミングが要求される処理を確実に実行できます。

## References
*   [UNO Q | Arduino Documentation](https://docs.arduino.cc/hardware/uno-q)
*   [Working with Arduino Router RPC | Arduino Documentation](https://docs.arduino.cc/tutorials/uno-q/routerbridge-multilanguage/)

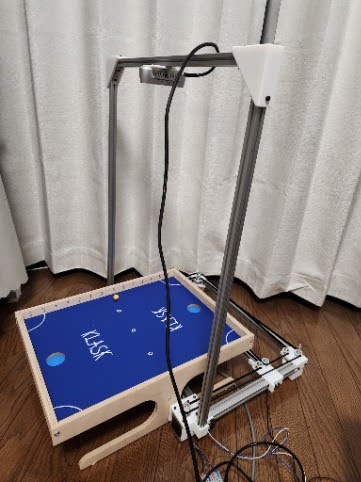
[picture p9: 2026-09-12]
assets/roboklask.jpg

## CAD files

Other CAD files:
hardware/LimitSwitchMount.stl
hardware/CameraAngle.stl
hardware/Arm_Holder.stl
hardware/MotorMount_L.stl
hardware/PulleyMountA_L.stl
hardware/PulleyMountB.stl
hardware/Stopper.stl
hardware/RealSenseMounter.stl
hardware/Leg.stl
hardware/PulleyMountC.stl
hardware/MotorMount_R.stl
hardware/PulleyMountA_R.stl

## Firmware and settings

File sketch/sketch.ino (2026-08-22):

#include <AccelStepper.h>
#if defined(ARDUINO_UNO_Q)
#include <Arduino_RouterBridge.h>
#include <zephyr/kernel.h>

#include "matrix.h"
Arduino_LED_Matrix matrix;
K_MUTEX_DEFINE(head_mutex);
K_MUTEX_DEFINE(ball_mutex);
#elif defined(ARDUINO_MINIMA)
#include "serial_bridge.hpp"
SerialBridge bridge(Serial, 115200);
#endif

#include <vector>

#include "pinout.h"
#include "xycontrol.hpp"

XYControl xyControl(MX_STEP, MX_DIR, MY_STEP, MY_DIR, SW_X, SW_Y);

Position new_head_pos;
Position head_pos;
Position ball_pos; // 追加: loopでの描画用

void blinkLED(int count) {
  for (int i = 0; i < count; i++) {
    digitalWrite(LED_BUILTIN, LOW); // 点灯 (LOW=ON)
    delay(100);
    digitalWrite(LED_BUILTIN, HIGH); // 消灯 (HIGH=OFF)
    delay(100);
  }
  delay(500);
}

unsigned long now = 0;
unsigned long last_update_ms = 0;
constexpr uint8_t CYCLE_ms = 33;

void setup() {
  // 1. 最優先でLEDピンを初期化して消灯(HIGH=OFF)にする
  pinMode(LED_BUILTIN, OUTPUT);
  digitalWrite(LED_BUILTIN, HIGH);

  // PC接続用シリアルデバッグの開始
  Serial.begin(115200);
  for (int i = 0; i < 10 && !Serial; i++) {
    delay(100);
  }
  Serial.println("MCU Started.");

  blinkLED(1); // 1回点滅: setup開始成功 (消灯で終了)

#if defined(ARDUINO_UNO_Q)
  // LED Matrixの初期化のみ最初に行う
  matrix.begin();
  matrix.setGrayscaleBits(1);
  matrix.clear();
#endif

  pinMode(SW_X, INPUT_PULLUP);
  pinMode(SW_Y, INPUT_PULLUP);

  pinMode(nEN, OUTPUT);
  digitalWrite(nEN, HIGH);

  // M0, M1, M2ピンの出力を明示的に設定
  pinMode(M0, OUTPUT);
  digitalWrite(M0, setM0);
  pinMode(M1, OUTPUT);
  digitalWrite(M1, setM1);
  pinMode(M2, OUTPUT);
  digitalWrite(M2, setM2);

  blinkLED(2); // 2回点滅: ピン初期設定完了、Homing直前

  // 2. キャリブレーションの実行
  digitalWrite(LED_BUILTIN, LOW); // Homing開始: 点灯 (LOW=ON)
  Serial.println("Starting homing...");
  xyControl.homing();
  digitalWrite(LED_BUILTIN, HIGH); // Homing完了: 消灯 (HIGH=OFF)
  Serial.println("Homing finished.");

  // 四隅巡回テストの実行
  digitalWrite(LED_BUILTIN, LOW); // 四隅テスト開始: 点灯 (LOW=ON)
  Serial.println("Starting test corners...");
  xyControl.testCorners();
  digitalWrite(LED_BUILTIN, HIGH); // 四隅テスト完了: 消灯 (HIGH=OFF)
  Serial.println("Test corners finished.");

  blinkLED(3); // 3回点滅: Homing&Test完了、通信初期化直前

  // 3. モーターのすべての初期位置合わせが完了した後に、通信を開始する
#if defined(ARDUINO_UNO_Q)
  Bridge.begin();

  Bridge.provide("py2mcu", [](std::vector<float> data) {
    if (data.size() < 4)
      return;
    k_mutex_lock(&head_mutex, K_FOREVER);
    new_head_pos.x = constrain(data[0], -1.0f, 1.0f);
    new_head_pos.y = constrain(data[1], 0.0f, 1.0f);
    k_mutex_unlock(&head_mutex);

    k_mutex_lock(&ball_mutex, K_FOREVER);
    ball_pos.x = data[2];
    ball_pos.y = data[3];
    k_mutex_unlock(&ball_mutex);

    // データ受信のたびにLEDをトグルして、受信割り込みの動作を目視確認する
    static bool ledState = false;
    ledState = !ledState;
    digitalWrite(LED_BUILTIN, ledState ? LOW : HIGH); // LOW=ON, HIGH=OFF
  });

  Monitor.begin(); // クラッシュ回避のためコメントアウト
#elif defined(ARDUINO_MINIMA)
  bridge.begin();
#endif

  blinkLED(5); // 5回点滅: 通信初期化完了、setup正常終了

  // 初期ターゲットを中央に設定し、loop()突入時の引き戻しを防ぐ
  new_head_pos.x = 0.0f;
  new_head_pos.y = 0.25f;
  ball_pos.x = 0.0f;
  ball_pos.y = 0.0f;
}

Position local_new_head_pos;
Position local_ball_pos;

void loop() {
#if defined(ARDUINO_UNO_Q)
  unsigned long last_yield_ms = 0;
#endif

  while (true) {
    // 1. モーターのステップを更新（最優先・全力でポーリング）
    xyControl.run();

    unsigned long current_time = millis();

    // 2.
    // 33msに満たない場合は、通信受信とyieldのみ実行して即ループの先頭に戻る(continue)
    if (current_time - last_update_ms < CYCLE_ms) {
#if defined(ARDUINO_UNO_Q)
      if (Serial1.available() > 0) {
        safeUpdate();
      }
      if (current_time - last_yield_ms >= 1) {
        last_yield_ms = current_time;
        k_yield();
      }
#endif
      continue;
    }
    last_update_ms = current_time;

    // 3. 33ms経過時のメイン制御処理
    xyControl.getCurrentXY(head_pos);

#if defined(ARDUINO_UNO_Q)
    Bridge.notify("mcu2py", head_pos.x, head_pos.y);

    // 割り込みスレッドで更新されたターゲット座標を安全にコピーして、モーター制御に反映する
    k_mutex_lock(&head_mutex, K_FOREVER);
    local_new_head_pos = new_head_pos;
    k_mutex_unlock(&head_mutex);
    xyControl.move(local_new_head_pos);

    // LED Matrixの描画は、安全なメインスレッド(loop)側で実行する
    k_mutex_lock(&ball_mutex, K_FOREVER);
    local_ball_pos = ball_pos;
    k_mutex_unlock(&ball_mutex);
    xy(matrix, local_ball_pos.x, local_ball_pos.y);
#elif defined(ARDUINO_MINIMA)
    // Minima専用処理
    if (bridge.receive(new_head_pos)) {
      static bool ledState = false;
      ledState = !ledState;
    }
    bridge.sendPosition(head_pos);
    xyControl.move(new_head_pos);
#endif
  }
}

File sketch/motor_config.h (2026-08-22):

#ifndef MOTOR_CONFIG_H
#define MOTOR_CONFIG_H_

constexpr int setM0 = true;
constexpr int setM1 = true;
constexpr int setM2 = false;

// 1回転あたりのベースステップ数
constexpr int STEP = 400;
constexpr int resolution = 8;

// 盤面の可動最大ステップ数
constexpr int STEP_BACK_X = 100;   // X軸のソフトウェア可動範囲マージン
constexpr int STEP_BACK_Y = 200;   // Y軸のソフトウェア可動範囲マージン
constexpr int PHYSICAL_BACK = 300; // スイッチ解除のための物理的な戻り量
constexpr int XSTEP = 3100 * 2 + 500 - STEP_BACK_X * 2;
constexpr int YSTEP = 1500 * 2 + 100 - STEP_BACK_Y;

constexpr long HOMING_CHUNK = -10;

#endif // MOTOR_CONFIG_H_

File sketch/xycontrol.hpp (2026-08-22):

#ifndef XYCONTROL_HPP
#define XYCONTROL_HPP

#include <AccelStepper.h>
#include <Arduino.h>

#include "motor_config.h"
#

struct Position {
  float x;
  float y;
};

class XYControl {
private:
  AccelStepper stepper1;
  AccelStepper stepper2;
  int sw_x;
  int sw_y;
  long last_target_s1 = -999999;
  long last_target_s2 = -999999;

public:
  void setHomingSpeed() {
    stepper1.setMaxSpeed(STEP * 0.5 * resolution);
    stepper1.setAcceleration(STEP * 1.0 * resolution);
    stepper2.setMaxSpeed(STEP * 0.5 * resolution);
    stepper2.setAcceleration(STEP * 1.0 * resolution);
  }

  void setOperationalSpeed() {
    stepper1.setMaxSpeed(STEP * 5.0 * resolution);
    stepper2.setMaxSpeed(STEP * 5.0 * resolution);
    stepper1.setAcceleration(STEP * 8.0 * resolution);
    stepper2.setAcceleration(STEP * 8.0 * resolution);
  }

  XYControl(const int m1_step, const int m1_dir, const int m2_step,
            const int m2_dir, const int sw_x, const int sw_y)
      : stepper1(AccelStepper(1, m1_step, m1_dir)),
        stepper2(AccelStepper(1, m2_step, m2_dir)), sw_x(sw_x), sw_y(sw_y) {
    setHomingSpeed();
  }

  bool homing() {
    // ホーミング用の微小移動ステップ（0へ向かってマイナスに進む）
    // 安全のためのキャリブレーション用低速設定
    setHomingSpeed();

    // ==========================================
    // STEP 1: 左右リセット (SW_X が HIGH になるまでマイナス駆動)
    // ==========================================
    // 配線反転により、これが物理的な左右リセット方向になります
    // 大きな目的地を指定して、スムーズに加速・巡航させます
    stepper1.move(-10000 * resolution);
    stepper2.move(10000 * resolution);

    while (digitalRead(sw_x) == LOW) {
      stepper1.run();
      stepper2.run();
    }

    // 即座にパルス送信を終了する（減速のためのオーバーランを防ぐ）
    stepper1.setCurrentPosition(stepper1.currentPosition());
    stepper2.setCurrentPosition(stepper2.currentPosition());

    // スイッチ解放（プラス側へ戻す）
    stepper1.move(PHYSICAL_BACK * resolution);
    stepper2.move(-PHYSICAL_BACK * resolution);
    while (stepper1.distanceToGo() != 0 || stepper2.distanceToGo() != 0) {
      stepper1.run();
      stepper2.run();
    }
    delay(200);

    // ==========================================
    // STEP 2: 前後リセット (SW_Y が HIGH になるまでマイナス駆動)
    // ==========================================
    // 両方マイナス駆動
    stepper1.move(-10000 * resolution);
    stepper2.move(-10000 * resolution);

    while (digitalRead(sw_y) == LOW) {
      stepper1.run();
      stepper2.run();
    }

    // 即座にパルス送信を終了する（減速のためのオーバーランを防ぐ）
    stepper1.setCurrentPosition(stepper1.currentPosition());
    stepper2.setCurrentPosition(stepper2.currentPosition());

    // スイッチ解放（プラス側へ戻す）
    stepper1.move(PHYSICAL_BACK * resolution);
    stepper2.move(PHYSICAL_BACK * resolution);
    while (stepper1.distanceToGo() != 0 || stepper2.distanceToGo() != 0) {
      stepper1.run();
      stepper2.run();
    }
    delay(200);

    // ★ここで最初で最後の原点設定。
    // スイッチから完全に離脱した「この安全な隅」こそが、真の (0, 0) です。
    Serial.println("homing: setting current positions to 0");
    resetCoordinates();
    delay(500);

    // 本番用の設定に引き上げる（脱調防止のため、速度・加速度をマイルドに設定）
    Serial.println("homing: configuring operational speeds");
    setOperationalSpeed();
    Serial.println("homing: complete");
    return true;
  }

  void move(const Position &pos) {
    // 1. 万が一範囲外の数値が来ても盤面から飛び出さないようにクリップする
    float clipped_x = constrain(pos.x, -1.0f, 1.0f);
    float clipped_y = constrain(pos.y, 0.0f, 1.0f);

    // 2. 正規化座標を絶対ステップ数（0〜XSTEP/YSTEP）に変換する
    float x_0_to_1 = (clipped_x + 1.0f) / 2.0f;
    long target_step_x = (long)(XSTEP * x_0_to_1);
    long target_step_y = (long)(YSTEP * clipped_y);

    long target_s1 = (target_step_x + target_step_y) * resolution;
    long target_s2 = (-target_step_x + target_step_y) * resolution;

    // 3. 実際の目標ステップ位置が変化したときだけ moveTo
    // を実行し、加速リセットを防ぐ
    if (target_s1 != last_target_s1 || target_s2 != last_target_s2) {
      stepper1.moveTo(target_s1);
      stepper2.moveTo(target_s2);
      last_target_s1 = target_s1;
      last_target_s2 = target_s2;
    }
  }

  void gotoCenter() {
    // X=0.0f (中央), Y=1.0f
    move({0.0f, 1.0f});

    while (stepper1.distanceToGo() != 0 || stepper2.distanceToGo() != 0) {
      this->run();
    }
  }

  void testCorners() {
    Serial.println("testCorners: setting to operational (high) speed");
    setOperationalSpeed(); // テスト走行の速度を本番速度へ引き上げ

    const Position corners[] = {
        {-1.0f, 0.0f}, // 左手前
        {-1.0f, 1.0f}, // 左奥
        {1.0f, 1.0f},  // 右奥
        {1.0f, 0.0f}   // 右手前
    };

    for (const auto &corner : corners) {
      Serial.print("testCorners: target -> x=");
      Serial.print(corner.x);
      Serial.print(", y=");
      Serial.println(corner.y);

      move(corner);

      while (stepper1.distanceToGo() != 0 || stepper2.distanceToGo() != 0) {
        stepper1.run();
        stepper2.run();
      }

      delay(1000); // 動作確認のために各角で1秒静止
    }

    Serial.println("testCorners: restoring operational speed");
  }

  void getCurrentXY(Position &pos) {
    long s1 = stepper1.currentPosition();
    long s2 = stepper2.currentPosition();
    // H-bot逆変換:
    //   s1 = (sx + sy) * resolution
    //   s2 = (-sx + sy) * resolution
    // → sx = (s1 - s2) / (2 * resolution)
    // → sy = (s1 + s2) / (2 * resolution)
    long sx = (s1 - s2) / (2 * resolution);
    long sy = (s1 + s2) / (2 * resolution);
    // X軸: 0.0〜1.0 から -1.0〜1.0 へ逆マッピング
    float x_0_to_1 = (float)sx / XSTEP;
    pos.x = x_0_to_1 * 2.0f - 1.0f;
    pos.y = (float)sy / YSTEP;
  }

  void resetX() {
    // sw_x に激突して PHYSICAL_BACK 戻った状態で呼ばれる。
    // この位置の x 座標を (PHYSICAL_BACK - STEP_BACK_X) と定義し、y
    // 座標は現在の値を保持する。 H-bot: x = (s1 - s2)/(2*res), y = (s1 +
    // s2)/(2*res)
    long current_s1 = stepper1.currentPosition();
    long current_s2 = stepper2.currentPosition();
    long current_y = (current_s1 + current_s2) / (2 * resolution);
    long setup_x = PHYSICAL_BACK - STEP_BACK_X;

    stepper1.setCurrentPosition((setup_x + current_y) * resolution);
    stepper2.setCurrentPosition((-setup_x + current_y) * resolution);
  }

  void resetY() {
    // sw_y に激突して PHYSICAL_BACK 戻った状態で呼ばれる。
    // この位置の y 座標を (PHYSICAL_BACK - STEP_BACK_Y) と定義し、x
    // 座標は現在の値を保持する。
    long current_s1 = stepper1.currentPosition();
    long current_s2 = stepper2.currentPosition();
    long current_x = (current_s1 - current_s2) / (2 * resolution);
    long setup_y = PHYSICAL_BACK - STEP_BACK_Y;

    stepper1.setCurrentPosition((current_x + setup_y) * resolution);
    stepper2.setCurrentPosition((-current_x + setup_y) * resolution);
  }

  void resetCoordinates() {
    // 左右・前後ともに PHYSICAL_BACK 戻った位置で呼ばれる。
    // この位置の座標を x = (PHYSICAL_BACK - STEP_BACK_X), y = (PHYSICAL_BACK -
    // STEP_BACK_Y) と定義する。
    long setup_x = PHYSICAL_BACK - STEP_BACK_X;
    long setup_y = PHYSICAL_BACK - STEP_BACK_Y;

    stepper1.setCurrentPosition((setup_x + setup_y) * resolution);
    stepper2.setCurrentPosition((-setup_x + setup_y) * resolution);
  }
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

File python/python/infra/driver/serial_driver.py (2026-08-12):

import logging
import math
import struct

import serial

from python.domain.config import SerialConfig
from python.domain.model.robot_xy import RobotXY
from python.domain.model.shared import Shared
from python.domain.runtime import Runtime

logger = logging.getLogger(__name__)


class SerialDriver:
    def __init__(self, shared: Shared, use_onnx: bool = True) -> None:
        sc = SerialConfig()

        self.port = sc.serial_port
        self.baudrate = sc.baudrate
        self.shared = shared
        self.predict = Runtime(use_onnx=use_onnx)

        # self.serial_connection = None

        self.ser = serial.Serial(self.port, self.baudrate, timeout=1)

    def send_target(self, target: RobotXY) -> None:
        if not self.ser.is_open:
            return

        target_x = target.x
        target_y = target.y

        try:
            # Packet structure (9 bytes total):
            # - Header: 0xAA (1 byte, unsigned char)
            # - X position target: float (4 bytes, Little-Endian)
            # - Y position target: float (4 bytes, Little-Endian)
            packet = struct.pack("<Bff", 0xAA, target_x, target_y)
            logger.debug(f"TX target -> MCU (Serial): x={target_x:.4f}, y={target_y:.4f}")
            self.ser.write(packet)
            self.ser.flush()
        except Exception as e:
            logger.error(f"Error writing binary packet to serial port {self.port}: {e}")

    def read_feedback(self) -> RobotXY | None:
        if not self.ser.is_open:
            return None

        try:
            bytes_to_read = self.ser.in_waiting
            if bytes_to_read < 9:
                return None

            data = self.ser.read(bytes_to_read)

            # Search backwards from the end of the buffer to extract the most recent valid packet.
            # A valid packet starts with 0xAA (integer 170) followed by 8 bytes of payload.
            idx = len(data) - 9
            while idx >= 0:
                if data[idx] == 0xAA:
                    x_val, y_val = struct.unpack("<ff", data[idx + 1 : idx + 9])
                    if not (math.isnan(x_val) or math.isnan(y_val) or math.isinf(x_val) or math.isinf(y_val)):
                        feedback = RobotXY(
                            x=max(-1.0, min(1.0, float(x_val))),
                            y=max(-1.0, min(1.0, float(y_val))),
                        )
                        logger.debug(f"RX feedback <- MCU (Serial): x={feedback.x:.4f}, y={feedback.y:.4f}")
                        return feedback
                idx -= 1

        except Exception as e:
            logger.error(f"Error reading feedback from serial port: {e}")

        return None

    def run(self) -> None:
        logger.info(f"Starting SerialDriver on {self.port} at {self.baudrate}...")
        while True:
            fb = self.read_feedback()

            if fb is not None:
                with self.shared.lock:
                    self.shared.striker = fb
                    ba = self.shared.ball
                st = fb
            else:
                with self.shared.lock:
                    st = self.shared.striker
                    ba = self.shared.ball

            resp = self.predict.predict(ba, st)
            self.send_target(resp)

    def stop(self) -> None:
        if self.ser.is_open:
            try:
                self.ser.close()
                logger.info(f"MCU Serial Connection closed port {self.port}.")
            except Exception as e:
                logger.error(f"Error closing serial port {self.port}: {e}")

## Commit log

2026-06-02 範囲を変更
2026-06-02 CICDの整備 (#1)
    * update python
    * update python poe
    * add cpp lint
    * fix
    * update flow
    * update version
    * format
    * update cache strategy
2026-07-04 Squashed commit of the following:
    commit d670153b863d50470d9049e237766eb9361d351d
    Author: motty <motty.mio2@gmail.com>
    Date: Sat Jul 4 16:27:23 2026 +0900
    fix pins
    commit 7285c9527ab011c1b7abeb8e94212323931b2d2e
    Author: motty <motty.mio2@gmail.com>
    Date: Sat Jul 4 14:49:37 2026 +0900
    pinのミスを治す
    commit 377b6ac9b30d331c559d219c61785e964397b72b
    Author: motty <motty.mio2@gmail.com>
    Date: Sun Jun 28 16:55:00 2026 +0900
    update devenv
    commit 11631dec6e06d99ccd7ae67ad86359e1527f7c8e
    Author: motty <motty.mio2@gmail.com>
    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
    [matrix.h, motor_config.h, sketch.ino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]
2026-08-12 接続 (#2)
    * update
    * output制御
    * xyをまとめる
    * build update
    * 画像処理を移植
    * remove pyrefly
    * update connection
    * update
    * add arduino uno q docs
    * timer counterの追加
    * ns をまとめる
    * fix root
    * feat: Configure RealSense for 60fps, enable OpenVINO GPU inference, and fix auto-calibration retry
    * feat: Implement multiprocess architecture for vision and control loop separation
    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
    [bridge_driver.py, matrix.h]
2026-08-19 feat/fix: Refactor motor control, adjust microstepping, and add corner tests (#6)
    * refactor: extract speed settings to helper methods in XYControl
    * fix: initialize new_head_pos to center to prevent sudden movement on startup
    * feat: implement figure-8 dummy path and increase stepper speed
    * fix: revert stepper speed to 10 and slow down dummy trajectory to prevent motor stall
    * fix: clamp feedback coordinates in bridge_driver to prevent pydantic validation errors
    * refactor: enable microstepping and reduce operational acceleration to mitigate belt slippage
    * fix: adjust microstepping to 1/4 step and rescale speed multipliers to prevent motor lock
    * fix: restore homing and operational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
    [bridge_driver.py, motor_config.h, sketch.ino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]
2026-08-22 feat(sketch): import cppcheck and formatting settings from applab_template (#4)
    * feat(sketch): import cppcheck and formatting settings from applab_template
    * fix: replace k_yield with safeUpdate to process RPC packets synchronously
    * tuning: lower send rate to 10Hz and increase operational speed/acceleration of stepper motors
    * tuning: adjust speed and acceleration to safer limits to prevent step loss
    * tuning: remove yields in blocking loops to maximize stepper speed, and add setup step indicators on BUILTIN LED
    * tuning: set resolution to 32 and guard safeUpdate with Serial1.available to resolve low-speed and layout issues
    * tuning: change microstep settings to full step (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
    [bridge_driver.py, motor_config.h, sketch.ino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]
2026-08-22 fix: change py2mcu RPC payload to std::vector<float> array to bypass Arduino template parameter count limits
    [bridge_driver.py, sketch.ino]
2026-09-06 docs(hardware): add 3D model hardware guide and bilingual READMEs (#8)
    * add docs
    * improve hw doc
    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
    [Arm_Holder.stl, CameraAngle.stl, Leg.stl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]
2026-09-12 feat(python): unify ONNX model path resolution and add model to assets via Git LFS (#9)
    - Support dynamic model path resolution for native and docker environments
    - Check /.dockerenv to determine execution environment
    - Update Runtime to use Config.model_path
    - Track *.onnx and *.onnx.data with Git LFS in .gitattributes
    - Remove unused inference_engine.py
2026-09-12 add docs (#7)
    * docs: create comprehensive README.md and README_ja.md for hackathon external sharing
    * docs: restructure readme and extract technical details to docs/optimizations
    * fix: change dynamic limit switch escape backup distance from STEP_BACK to PHYSICAL_BACK to match coordinate reset math
    * fix: add safeUpdate and k_yield inside dynamic limit switch escape loops to prevent communication hang during backoff
    * docs: document non-blocking limit switch escape logic in optimizations
    * update jp docs
    * add image
    * remove r4
    * r4 and q
    * add arduino applab support
    * revert: remove changes to xycontrol.hpp
